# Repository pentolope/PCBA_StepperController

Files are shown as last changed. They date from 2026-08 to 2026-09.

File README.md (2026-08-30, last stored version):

# Quiet Stepper Motor Controller

Single-axis stepper controller using a modern quiet microstepping driver and a small MCU, from a 12–24 V supply at 1.5 A RMS/phase minimum.

`PCBA_StepperController` is a single-axis stepper motor controller built around a modern quiet microstepping driver (the brief offers "a Trinamic-class device" as an example, not a mandate) and a small MCU. The brief fixes the supply range (12–24 V), the phase current target (1.5 A RMS/phase minimum), the presence of current-sense resistors and bulk/ceramic decoupling, STEP/DIR plus UART/SPI configuration access, fault/status signals, and a 4-pin motor connector; it also directs specific attention to driver thermal-pad grounding, high-current phase loops, and keeping current-sense routing away from switching nodes. Everything else — the actual driver and MCU parts, the logic rail, sense-resistor values, connector families, board outline, stackup details, protection and thermal strategy — is left to the design agent. At detail 3/5 this is a mid-specificity brief: the electrical envelope and the layout hazards are named, the implementation is not.

> **This board has not been designed.** There is no schematic, no layout and no
> part selection here — only the brief, a reading of the brief, and the
> scaffolding a design run needs. That is the intended state of this repository,
> not a gap in it.

## What the brief fixes, and what it leaves open

The brief pins down 16 requirements and deliberately leaves
19 decisions to whoever designs the board. The `Source` column says
which is which: `brief` is quoted from [BRIEF.md](BRIEF.md), `metadata` comes
from the benchmark catalogue, and `open` means the brief does not fix it.

| Aspect | Value | Source |
|---|---|---|
| Function | Single-axis stepper controller | brief |
| Motor driver | A modern quiet microstepping driver; a Trinamic-class device is given as an example only, not a mandated part | brief |
| Controller | A small MCU on the board | brief |
| Input supply | 12–24 V | brief |
| Motor current target | 1.5 A RMS/phase minimum | brief |
| Sensing and decoupling | Current-sense resistors plus bulk/ceramic decoupling (values and technologies not fixed) | brief |
| Control and configuration interfaces | STEP/DIR, and UART/SPI configuration access | brief |
| Fault/status | Fault/status signals present (form not fixed) | brief |
| Motor connector | 4-pin (family, pitch and rating not fixed) | brief |
| Layout emphasis called out by the brief | Driver thermal-pad grounding, high-current phase loops, current-sense routing kept away from switching nodes | brief |
| Likely layer count | 4 preferred | metadata |
| Category / difficulty / brief detail | motor-control, difficulty 3, detail 3 | metadata |
| Primary stressors | motor-current routing, driver thermal pad, sense resistors, mixed-signal grounding | metadata |
| Board outline, size, mounting and power-input connector | Not fixed by the brief — design agent's choice | open |

The full split, with the verbatim brief text substantiating every fixed
requirement, is in [board/requirements.md](board/requirements.md) and
machine-readably in [board/requirements.json](board/requirements.json).

**Missing details are design freedom, not permission to fabricate unstated user
requirements.** A choice the brief left open is recorded as a decision, with its
reasoning — never promoted into a requirement.

## Benchmark position

| | |
|---|---|
| Benchmark id | 8 of 32 |
| Category | motor-control |
| Difficulty | 3 / 5 |
| Brief detail | 3 / 5 |
| Likely layer count | 4 preferred |
| Primary stressors | motor-current routing, driver thermal pad, sense resistors, mixed-signal grounding |

This is a motor-control board at difficulty 3/5 and detail 3/5: it tests whether an agent can carry a modest power stage from a stated current and supply envelope through conductor sizing, sense-resistor design and a defensible thermal path, rather than drawing a schematic that only looks right. The four named stressors — motor-current routing, driver thermal pad, sense resistors, mixed-signal grounding — are all layout-and-substantiation problems, so what separates a strong result from a plausible-looking one is whether the physical implementation and its supporting calculations agree. Because the brief names an example device class rather than a part, it also probes whether the agent treats an illustrative example as a requirement.

This repository is one of thirty-two. The suite, the protocol and the results
live in [PCBA_AutoDesignAndTest_Bench](https://github.com/pentolope/PCBA_AutoDesignAndTest_Bench).

## Repository layout

| Path | Contents |
|---|---|
| `BRIEF.md` | the supplied brief — authoritative, preserved byte for byte, never edited |
| `board/requirements.md` | what the brief fixes, what it leaves open, and where decisions get recorded |
| `board/requirements.json` | the same split, machine-readable, each fixed requirement bound to brief text |
| `board/manifest.template.json` | the toolkit's minimum manifest, pre-filled for this board |
| `board/toolchain.json` | where this board's build finds KiCad and the router |
| `benchmark/metadata.json` | the supplied catalogue entry — category, difficulty, detail, stressors |
| `docs/architecture.md` | the decisions this board must make, as questions, unanswered |
| `docs/sources.md` | the classes of evidence the design will have to cite |
| `docs/status.md` | what exists, what does not, and what is deliberately absent |
| `candidates/` | disposable search output, ignored by Git |
| `.claude/skills/` | the accountability-review skill [CLAUDE.md](CLAUDE.md) requires before a push |
| `tooling/PCBA_AutoDesignAndTest` | the shared verification/routing/release toolkit, as a pinned submodule |

## Getting the repository

The toolkit is a submodule and carries KiCad Routing Tools as a submodule of its
own, so clone recursively:

```bash
git clone --recursive https://github.com/pentolope/PCBA_StepperController.git
```

```bash
git submodule update --init --recursive
```

## Designing the board

Generic verification, routing and release logic is **not** written here. It is
consumed from `tooling/PCBA_AutoDesignAndTest`, which is board-agnostic by
construction and must stay that way; this repository owns the board and nothing
else. Start from
[the toolkit's onboarding guide](tooling/PCBA_AutoDesignAndTest/examples/onboarding.md),
and see [CLAUDE.md](CLAUDE.md) for the rules a design run works under.

```bash
python3 tooling/PCBA_AutoDesignAndTest/run.py preflight
```

## Brief integrity

`BRIEF.md` SHA-256 `eb32e622a2161815c687ef267615287b89c1135211a0c5d5494930910a460444`

Every quotation in `board/requirements.json` is bound to those exact bytes. If
the brief ever changes, the bindings are stale by construction — which is the
point of recording the digest.

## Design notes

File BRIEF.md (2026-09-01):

# PCBA_StepperController — Quiet Stepper Motor Controller
## Design brief

Create a single-axis stepper controller using a modern quiet microstepping driver (for example a Trinamic-class device) and a small MCU. Input supply: 12–24 V. Motor current target: 1.5 A RMS/phase minimum. Include current-sense resistors, bulk/ceramic decoupling, STEP/DIR and UART/SPI configuration access, fault/status signals, and a 4-pin motor connector. Pay particular attention to driver thermal-pad grounding, high-current phase loops, and keeping current-sense routing away from switching nodes.

## Functional and electrical requirements

- 1.5 A RMS/phase sustained continuously across the whole 12-24 V range.
- Low-noise microstepping usable as assembled; current, microstep resolution and chopper mode settable over the interface.
- Outputs off at power-up and reset; no phase current until the driver is explicitly enabled.

## Motor drive and current sensing

- One external sense resistor per phase, non-inductive, rated for peak and RMS dissipation, tempco and tolerance inside the recorded accuracy budget.
- Sense value puts 1.5 A RMS/phase (about 2.1 A sine peak) inside the driver's sense-voltage range, with programmable headroom either side.
- Kelvin sensing at the resistor pads, returning only to the driver's sense reference and sharing no copper with phase or supply return current.

## Interfaces and connectors

- 4-pin motor connector A+/A-/B+/B-, keyed against reversed mating, rated for phase current at temperature and retained against vibration.
- STEP/DIR meet the driver's pulse width and setup/hold limits and do not ring enough to double-step.
- Configuration interface carries the pulls and idle states the driver needs and is reachable externally for read-back; diagnostics reach the MCU, at least one interrupt-capable.

## Layout, grounding and thermal

- Exposed pad soldered to copper that is both power-ground connection and heat path, tied through a via array, not a neck or a sense return.
- Phase loops - output, connector, motor, return, sense resistor, ground - as tight as layout allows, enclosing no sense or logic routing.
- Sense pairs routed together, away from output nodes, phase copper and charge-pump nodes; decoupling for the shortest supply-to-ground loop.
- Copper area, plane tie and airflow hold junction temperature under the driver's limit with both phases at full current at 24 V.

## Protection and robustness

- Motor-supply parts rated above 24 V with margin for hot-plug ringing and regenerative rise; reversed polarity does no damage.
- Survives unmating the motor while enabled, and a phase shorted pin-to-pin, to ground or to supply.
- Driver short, open-load and overtemperature detection enabled and reported; drive latches off rather than retrying into a fault.

## Test and bring-up

- Test points with local ground on motor supply, logic rail, STEP, DIR, enable, fault/status and each sense node.
- Rails, register read-back and faults verifiable with no motor fitted; MCU debug accessible.

## Open choices

- Driver device and MCU, subject to quiet microstepping with external sense resistors at 1.5 A RMS/phase or more over 12-24 V and an interrupt-capable fault input.
- UART or SPI for configuration, and whether the logic rail is made on-board or taken from outside.
- Whether STEP/DIR are also exposed to an external motion source, and whether fault/status is surfaced to a human.
- Connector families, board outline and layer count.

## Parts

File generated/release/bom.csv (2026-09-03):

Quantity | Designator | Comment | Footprint | LCSC Part #
4 | C1,C2,C20,C21 | 100uF | Capacitor_SMD:CP_Elec_10x10.5 | C3008515
3 | C3,C4,C12 | 4.7uF | Capacitor_SMD:C_1206_3216Metric | C132170
10 | C5,C6,C8,C10,C11,C13,C14,C17,C18,C19 | 100nF | Capacitor_SMD:C_0603_1608Metric | C113803
1 | C7 | 22nF | Capacitor_SMD:C_0603_1608Metric | C106222
1 | C9 | 2.2uF | Capacitor_SMD:C_0805_2012Metric | C277470
2 | C15,C16 | 10uF | Capacitor_SMD:C_0805_2012Metric | C326595
1 | D1 | SMBJ26A | Diode_SMD:D_SMB | C315992
8 | D2,D3,D4,D5,D6,D7,D8,D9 | TPD1E10B06 | StepperController:TI_X1SON-2_1.0x0.6mm_P0.65mm | C48260
2 | D10,D11 | KT-0603R | LED_SMD:LED_0603_1608Metric | C2286
1 | J1 | KF128-5.08-2P-AA | StepperController:TerminalBlock_KF128-5.08_1x02_P5.08mm | C474952
1 | J2 | B4P-VH | Connector_JST:JST_VH_B4P-VH_1x04_P3.96mm_Vertical | C160317
2 | J3,J4 | KH-2.54PH180-1X5P-L11.5 | Connector_PinHeader_2.54mm:PinHeader_1x05_P2.54mm_Vertical | C2932699
1 | J5 | KH-2.54PH180-1X3P-L11.5 | Connector_PinHeader_2.54mm:PinHeader_1x03_P2.54mm_Vertical | C2932698
1 | L1 | 22uH | StepperController:L_Bourns_SRP4020TA | C1847949
1 | Q1 | Si9407BDY | Package_SO:SOIC-8_3.9x4.9mm_P1.27mm | C141567
5 | R1,R2,R3,R5,R7 | 100k | Resistor_SMD:R_0603_1608Metric | C25803
3 | R4,R6,R10 | 22k | Resistor_SMD:R_0603_1608Metric | C31850
1 | R8 | 12k | Resistor_SMD:R_0603_1608Metric | C22790
4 | R9,R20,R21,R22 | 1k | Resistor_SMD:R_0603_1608Metric | C21190
6 | R11,R12,R16,R17,R18,R19 | 100R | Resistor_SMD:R_0603_1608Metric | C22775
1 | R13 | 10k | Resistor_SMD:R_0603_1608Metric | C25804
2 | R14,R15 | 4.7k | Resistor_SMD:R_0603_1608Metric | C23162
2 | RS1,RS2 | 100mR | Resistor_SMD:R_1206_3216Metric | C5123673
1 | U1 | TMC2226-SA-T | StepperController:HTSSOP-28-1EP_4.4x9.7mm_P0.65mm_EP2.75x6.2mm_SegmentedMask | C705366
1 | U2 | STM32G030K8T6 | Package_QFP:LQFP-32_7x7mm_P0.8mm | C724044
1 | U3 | LMR51430YF | Package_TO_SOT_SMD:SOT-23-6 | C5219261

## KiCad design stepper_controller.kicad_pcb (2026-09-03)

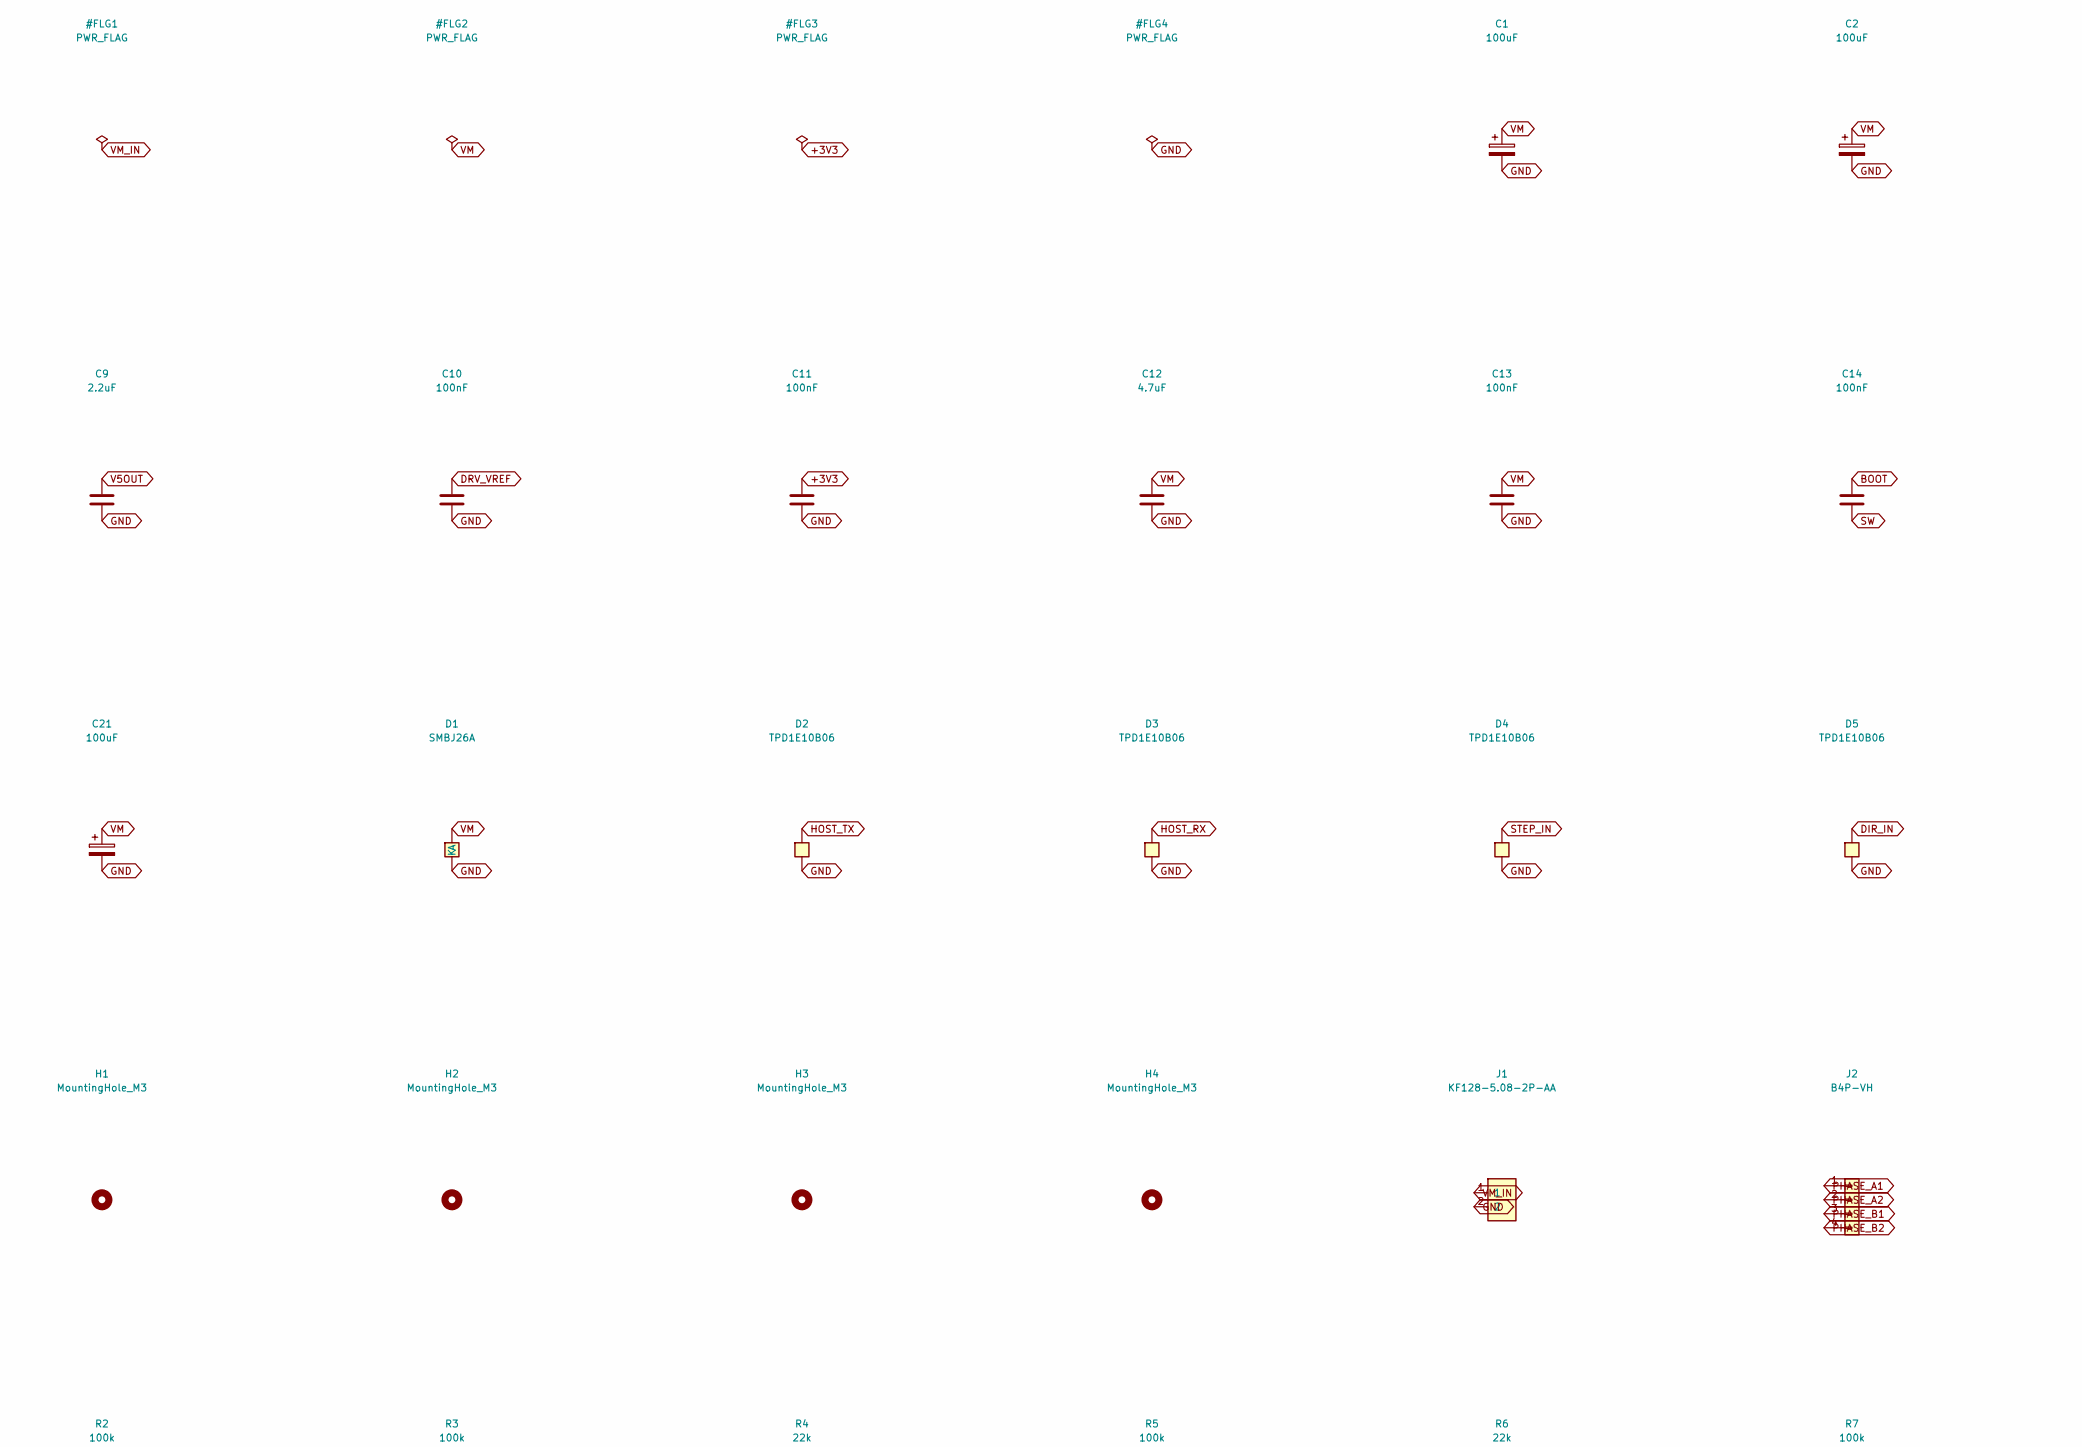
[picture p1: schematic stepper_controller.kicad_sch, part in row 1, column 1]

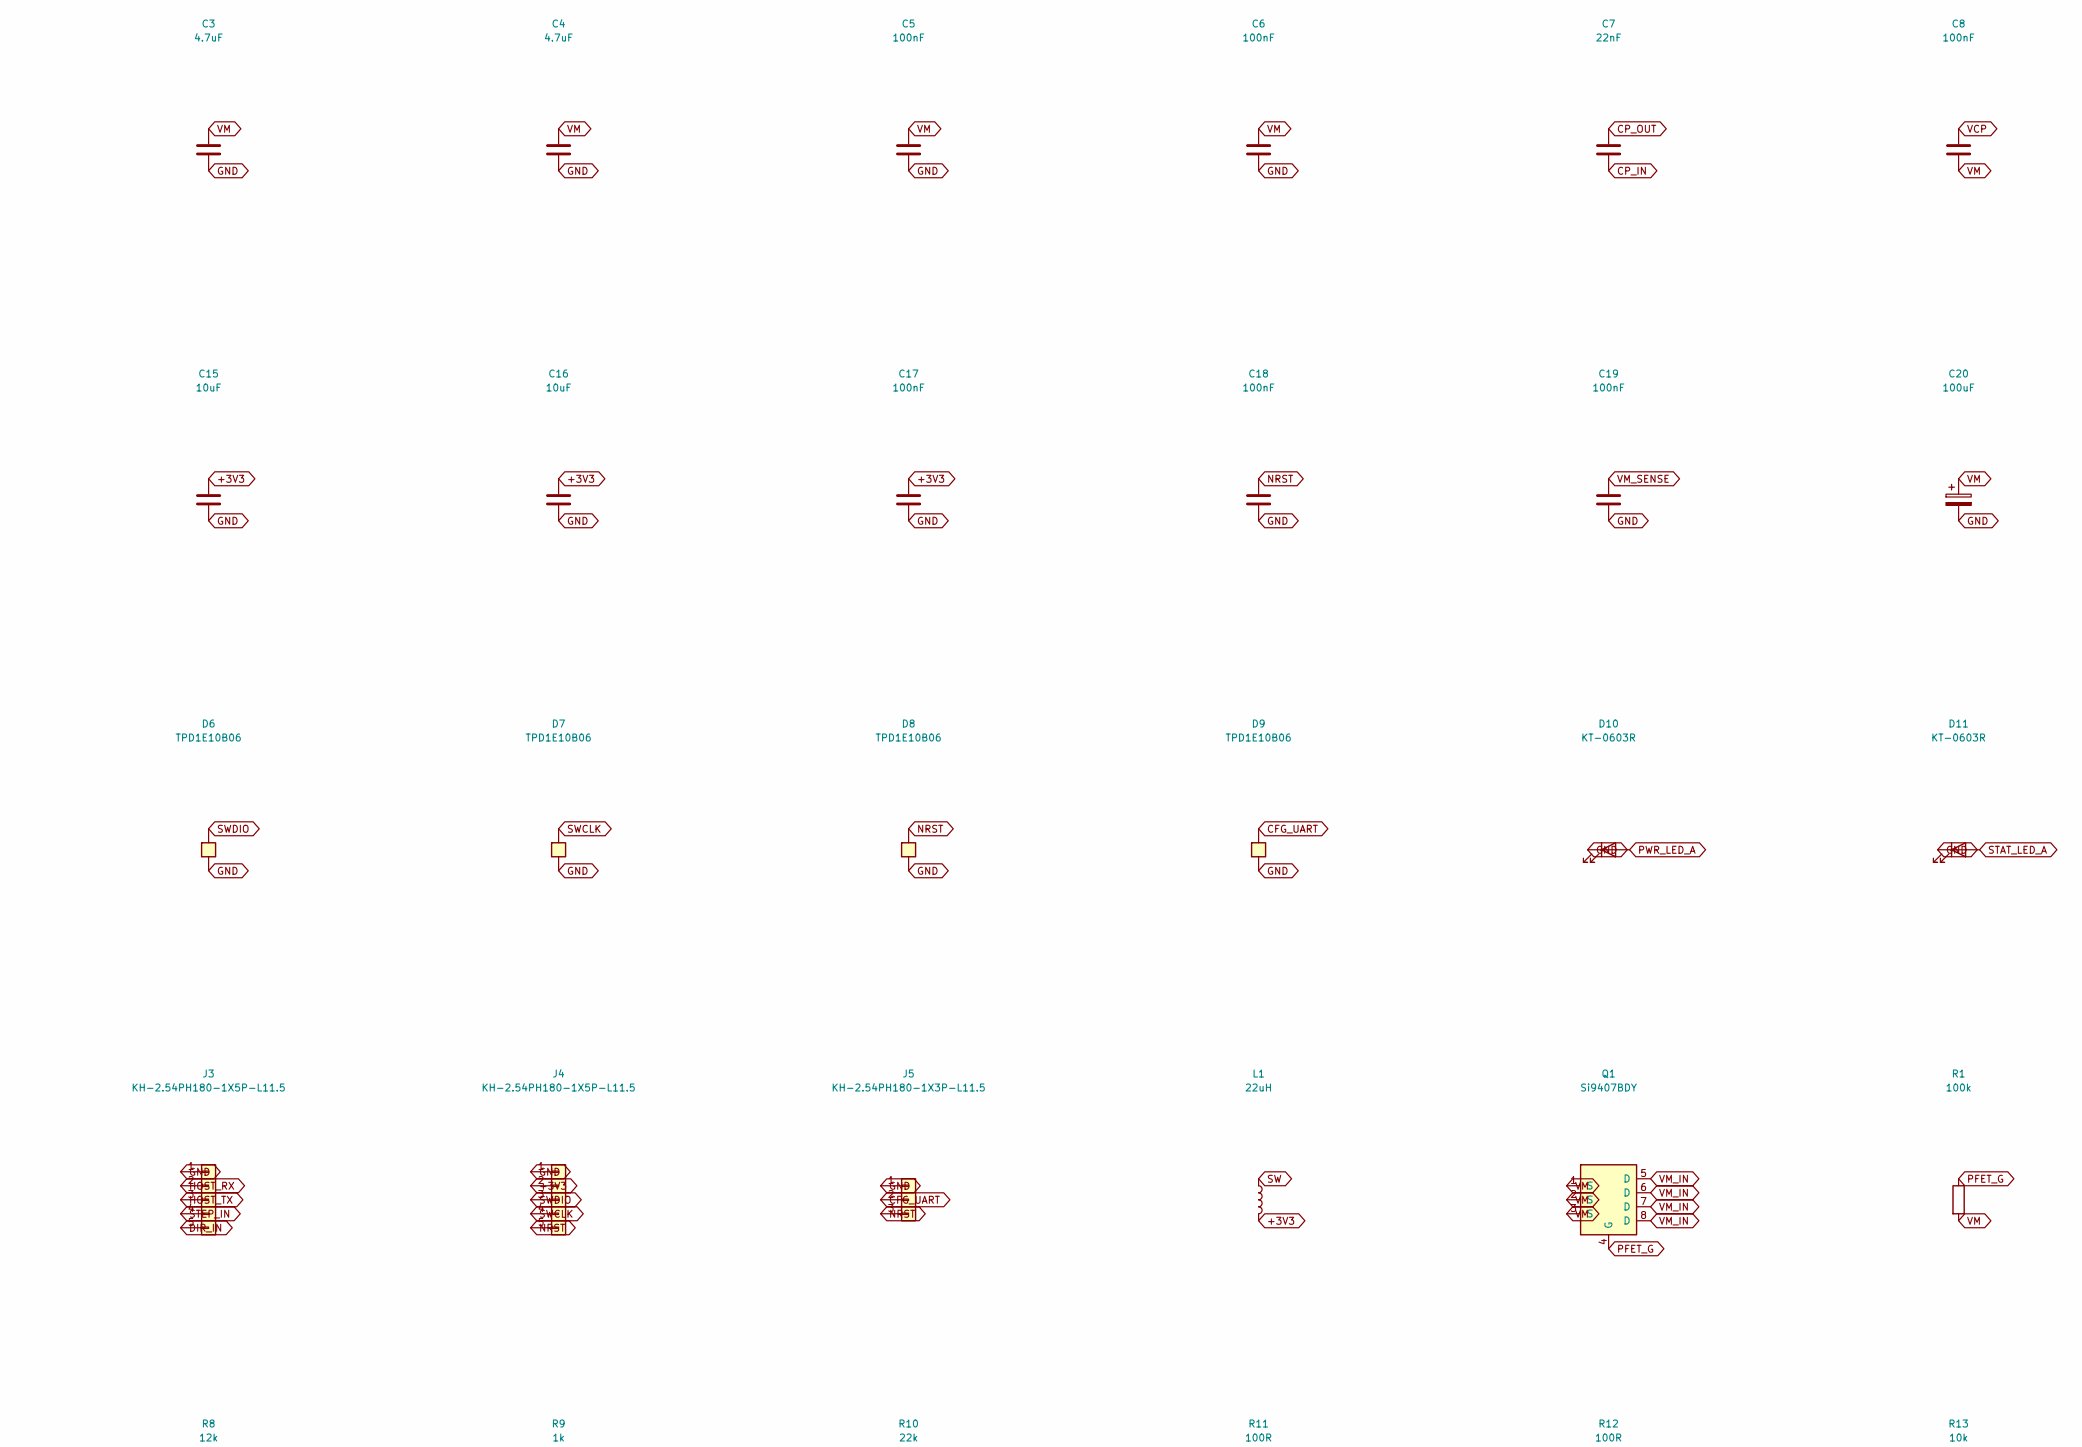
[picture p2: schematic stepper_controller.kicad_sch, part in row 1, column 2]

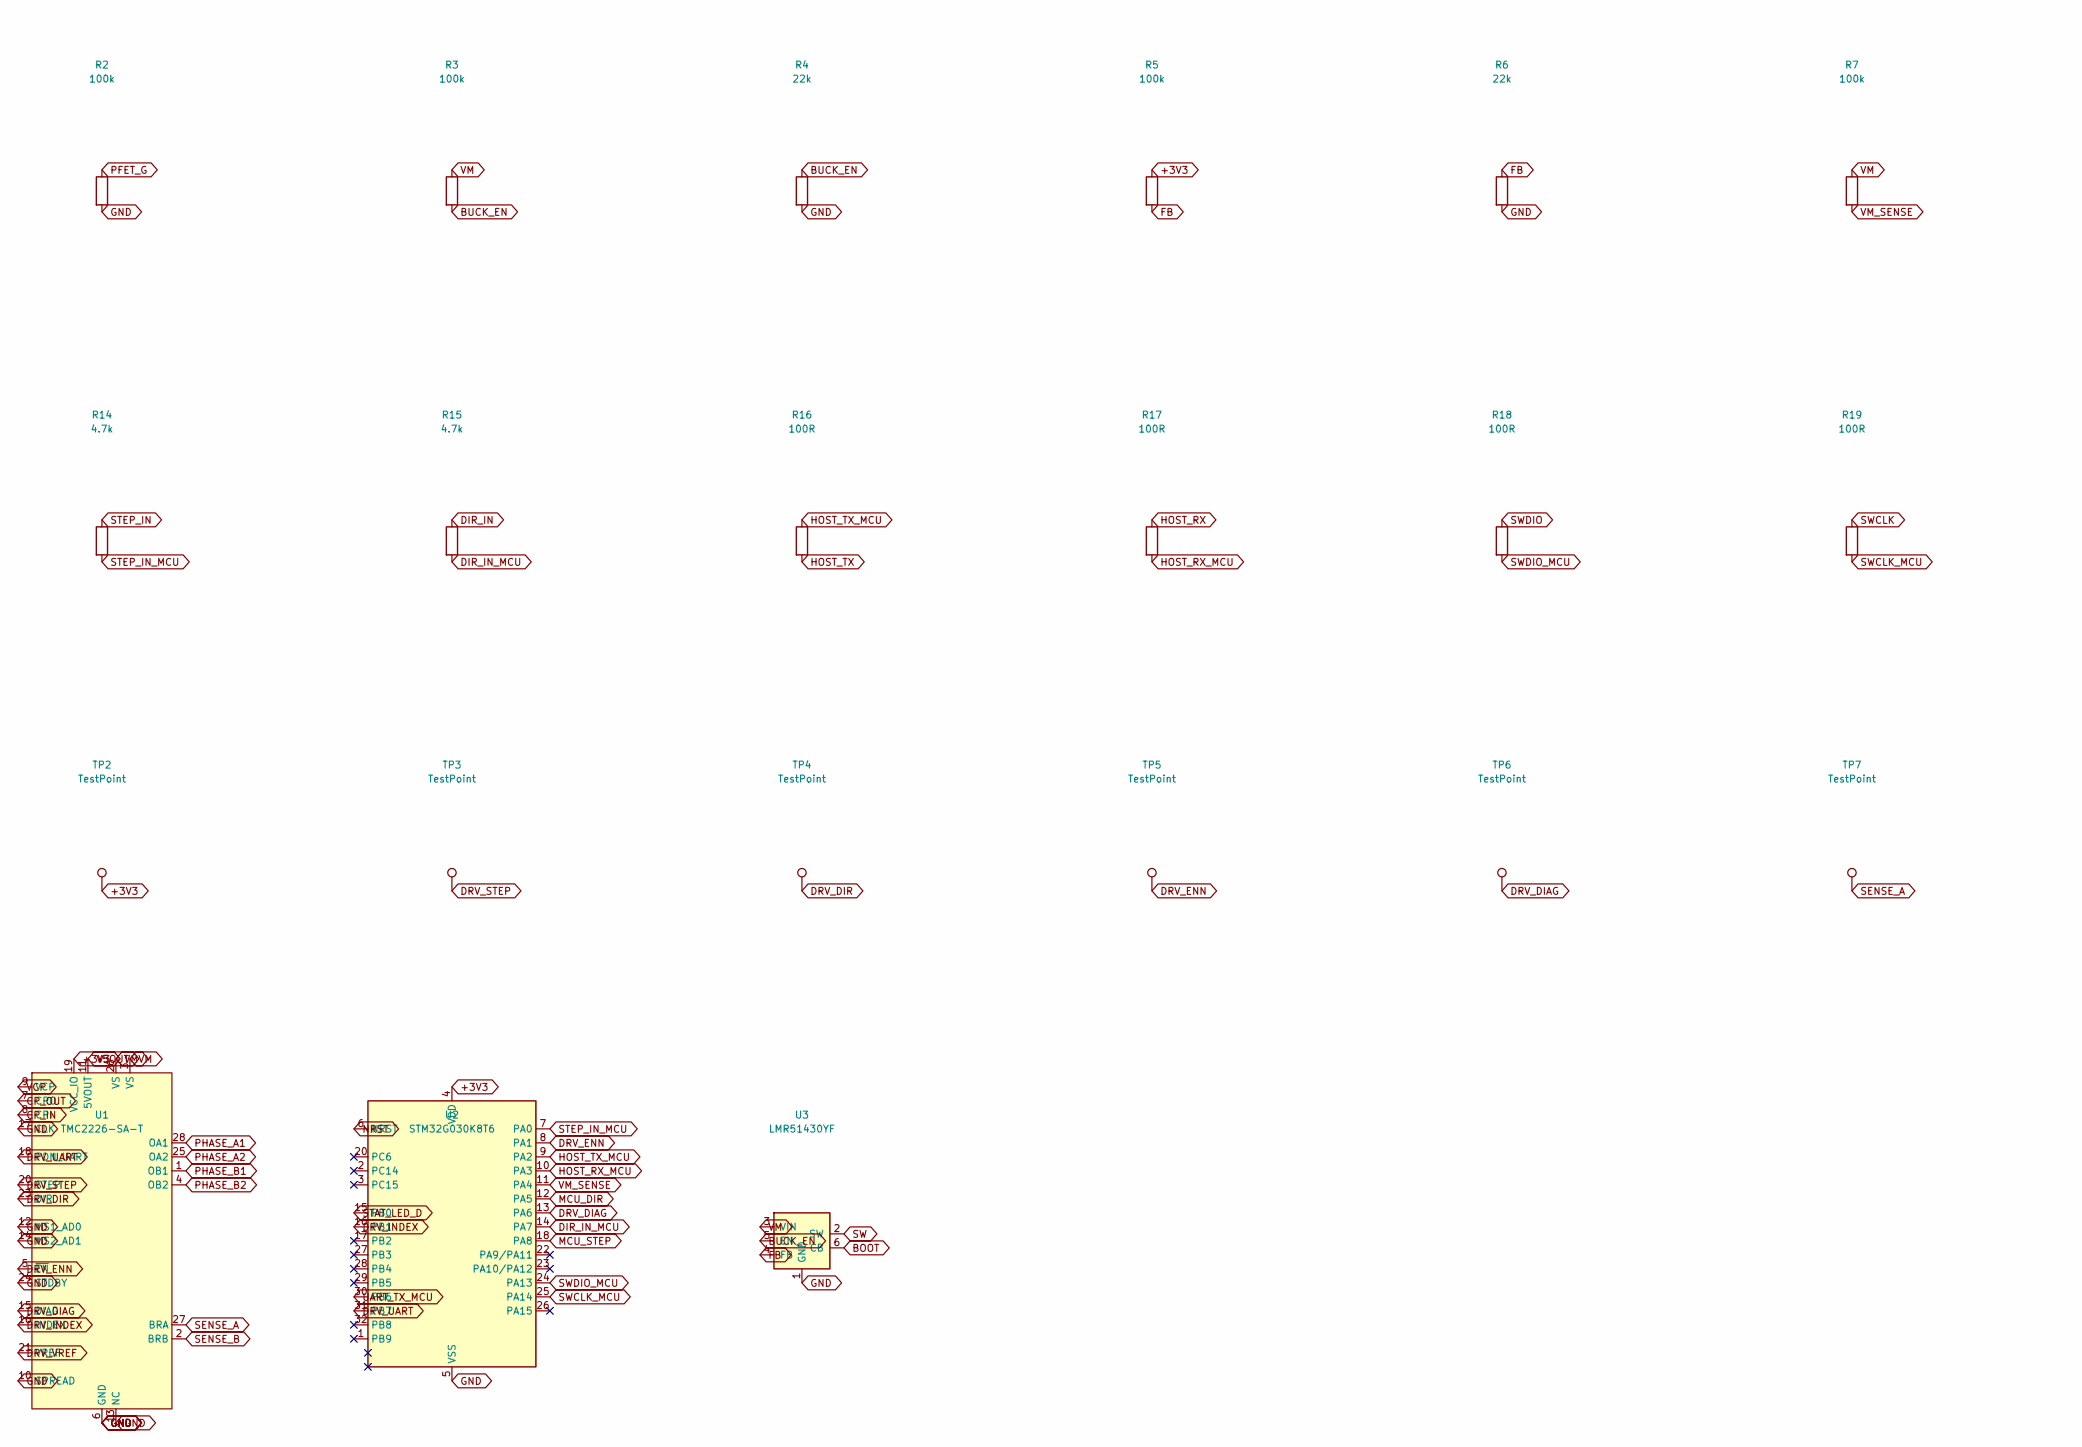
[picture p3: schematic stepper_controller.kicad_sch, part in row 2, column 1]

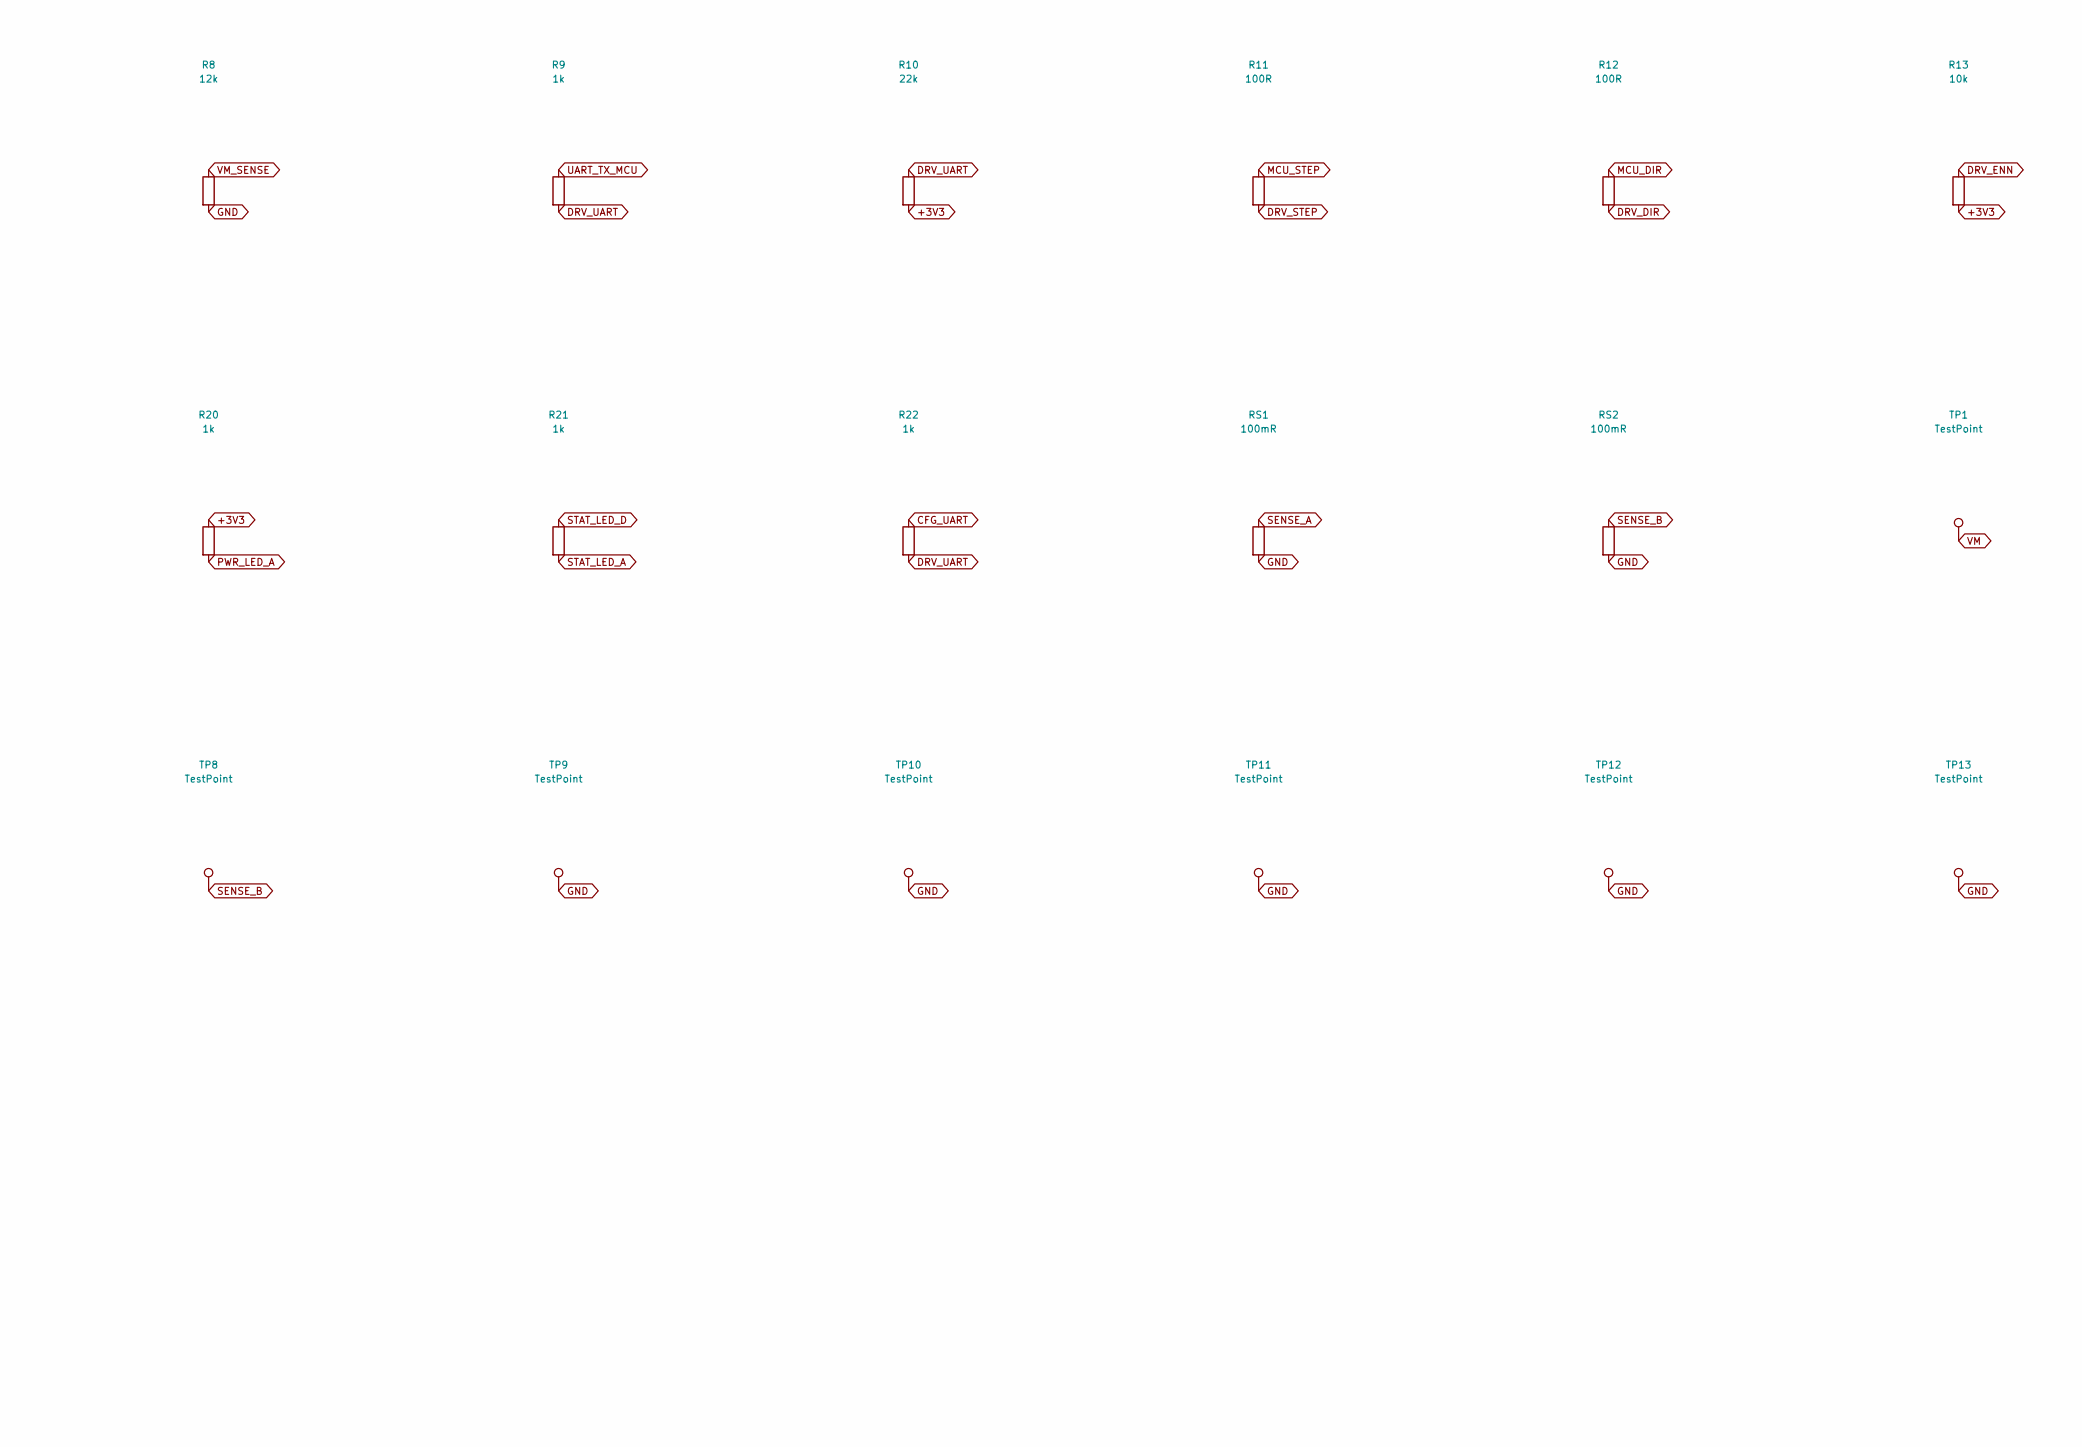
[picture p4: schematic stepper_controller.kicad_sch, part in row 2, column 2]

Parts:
C1, C2, C20, C21: 100uF; CP_Elec_10x10.5; MPN HHXC500ARA101MJA0G; LCSC C3008515
C3, C4, C12: 4.7uF; C_1206_3216Metric; MPN CC1206KKX7R9BB475; LCSC C132170
C5, C6, C8, C10, C11, C13, C14, C17, C18, C19: 100nF; C_0603_1608Metric; MPN CC0603KRX7R0BB104; LCSC C113803
C7: 22nF; C_0603_1608Metric; MPN CC0603KRX7R9BB223; LCSC C106222
C9: 2.2uF; C_0805_2012Metric; MPN CC0805KKX7R8BB225; LCSC C277470
C15, C16: 10uF; C_0805_2012Metric; MPN CC0805KKX7R7BB106; LCSC C326595
D1: SMBJ26A; D_SMB; MPN SMBJ26A; LCSC C315992
D2, D3, D4, D5, D6, D7, D8, D9: TPD1E10B06; TI_X1SON-2_1.0x0.6mm_P0.65mm; MPN TPD1E10B06DPYR; LCSC C48260
D10, D11: KT-0603R; LED_0603_1608Metric; MPN KT-0603R; LCSC C2286
H1, H2, H3, H4: MountingHole_M3; MountingHole_3.2mm_M3
J1: KF128-5.08-2P-AA; TerminalBlock_KF128-5.08_1x02_P5.08mm; MPN KF128-5.08-2P-AA; LCSC C474952
J2: B4P-VH; JST_VH_B4P-VH_1x04_P3.96mm_Vertical; MPN B4P-VH(LF)(SN); LCSC C160317
J3, J4: KH-2.54PH180-1X5P-L11.5; PinHeader_1x05_P2.54mm_Vertical; MPN KH-2.54PH180-1X5P-L11.5; LCSC C2932699
J5: KH-2.54PH180-1X3P-L11.5; PinHeader_1x03_P2.54mm_Vertical; MPN KH-2.54PH180-1X3P-L11.5; LCSC C2932698
L1: 22uH; L_Bourns_SRP4020TA; MPN SRP4020TA-220M; LCSC C1847949
Q1: Si9407BDY; SOIC-8_3.9x4.9mm_P1.27mm; MPN Si9407BDY-T1-GE3; LCSC C141567
R1, R2, R3, R5, R7: 100k; R_0603_1608Metric; MPN 0603WAF1003T5E; LCSC C25803
R4, R6, R10: 22k; R_0603_1608Metric; MPN 0603WAF2202T5E; LCSC C31850
R8: 12k; R_0603_1608Metric; MPN 0603WAF1202T5E; LCSC C22790
R9, R20, R21, R22: 1k; R_0603_1608Metric; MPN 0603WAF1001T5E; LCSC C21190
R11, R12, R16, R17, R18, R19: 100R; R_0603_1608Metric; MPN 0603WAF1000T5E; LCSC C22775
R13: 10k; R_0603_1608Metric; MPN 0603WAF1002T5E; LCSC C25804
R14, R15: 4.7k; R_0603_1608Metric; MPN 0603WAF4701T5E; LCSC C23162
RS1, RS2: 100mR; R_1206_3216Metric; MPN HoLRTX1206-1W-100mR-1%; LCSC C5123673
TP1, TP2, TP3, TP4, TP5, TP6, TP7, TP8, TP9, TP10, TP11, TP12, TP13: TestPoint; TestPoint_Pad_D1.0mm
U1: TMC2226-SA-T; HTSSOP-28-1EP_4.4x9.7mm_P0.65mm_EP2.75x6.2mm_SegmentedMask; MPN TMC2226-SA-T; LCSC C705366
U2: STM32G030K8T6; LQFP-32_7x7mm_P0.8mm; MPN STM32G030K8T6TR; LCSC C724044
U3: LMR51430YF; SOT-23-6; MPN LMR51430YFDDCR; LCSC C5219261

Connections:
+3V3: C11.1, C15.1, C16.1, C17.1, J4.2, L1.2, R5.1, R10.2, R13.2, R20.1, TP2.1, U1.19 (VCC_IO), U2.4 (VDD)
BOOT: C14.1, U3.6 (CB)
BUCK_EN: R3.2, R4.1, U3.5 (EN)
CFG_UART: D9.1 (IO1), J5.2, R22.1
CP_IN: C7.2, U1.8 (CPI)
CP_OUT: C7.1, U1.7 (CPO)
DIR_IN: D5.1 (IO1), J3.5, R15.1
DIR_IN_MCU: R15.2, U2.14 (PA7)
DRV_DIAG: TP6.1, U1.15 (DIAG), U2.13 (PA6)
DRV_DIR: R12.2, TP4.1, U1.23 (DIR)
DRV_ENN: R13.1, TP5.1, U1.5 (~EN), U2.8 (PA1)
DRV_INDEX: U1.16 (INDEX), U2.16 (PB1)
DRV_STEP: R11.2, TP3.1, U1.20 (STEP)
DRV_UART: R9.2, R10.1, R22.2, U1.18 (PDN_UART), U2.31 (PB7)
DRV_VREF: C10.1, U1.21 (VREF)
FB: R5.2, R6.1, U3.4 (FB)
GND: C1.2, C2.2, C3.2, C4.2, C5.2, C6.2, C9.2, C10.2, C11.2, C12.2, C13.2, C15.2, C16.2, C17.2, C18.2, C19.2, C20.2, C21.2, D1.2 (A), D2.2 (IO2), D3.2 (IO2), D4.2 (IO2), D5.2 (IO2), D6.2 (IO2), D7.2 (IO2), D8.2 (IO2), D9.2 (IO2), D10.1 (K), D11.1 (K), J1.2, J3.1, J4.1, J5.1, R2.2, R4.2, R6.2, R8.2, RS1.2, RS2.2, TP9.1, TP10.1, TP11.1, TP12.1, TP13.1, U1.6 (GND), U1.10 (SPREAD), U1.12 (MS1_AD0), U1.13 (NC), U1.14 (MS2_AD1), U1.17 (CLK), U1.22 (GND), U1.24 (STDBY), U1.29 (GND), U2.5 (VSS), U3.1 (GND)
HOST_RX: D3.1 (IO1), J3.2, R17.1
HOST_RX_MCU: R17.2, U2.10 (PA3)
HOST_TX: D2.1 (IO1), J3.3, R16.2
HOST_TX_MCU: R16.1, U2.9 (PA2)
MCU_DIR: R12.1, U2.12 (PA5)
MCU_STEP: R11.1, U2.18 (PA8)
NRST: C18.1, D8.1 (IO1), J4.5, J5.3, U2.6 (NRST)
PFET_G: Q1.4 (G), R1.1, R2.1
PHASE_A1: J2.1, U1.28 (OA1)
PHASE_A2: J2.2, U1.25 (OA2)
PHASE_B1: J2.3, U1.1 (OB1)
PHASE_B2: J2.4, U1.4 (OB2)
PWR_LED_A: D10.2 (A), R20.2
SENSE_A: RS1.1, TP7.1, U1.27 (BRA)
SENSE_B: RS2.1, TP8.1, U1.2 (BRB)
STAT_LED_A: D11.2 (A), R21.2
STAT_LED_D: R21.1, U2.15 (PB0)
STEP_IN: D4.1 (IO1), J3.4, R14.1
STEP_IN_MCU: R14.2, U2.7 (PA0)
SW: C14.2, L1.1, U3.2 (SW)
SWCLK: D7.1 (IO1), J4.4, R19.1
SWCLK_MCU: R19.2, U2.25 (PA14)
SWDIO: D6.1 (IO1), J4.3, R18.1
SWDIO_MCU: R18.2, U2.24 (PA13)
UART_TX_MCU: R9.1, U2.30 (PB6)
V5OUT: C9.1, U1.11 (5VOUT)
VCP: C8.1, U1.9 (VCP)
VM: C1.1, C2.1, C3.1, C4.1, C5.1, C6.1, C8.2, C12.1, C13.1, C20.1, C21.1, D1.1 (K), Q1.1 (S), Q1.2 (S), Q1.3 (S), R1.2, R3.1, R7.1, TP1.1, U1.3 (VS), U1.26 (VS), U3.3 (VIN)
VM_IN: J1.1, Q1.5 (D), Q1.6 (D), Q1.7 (D), Q1.8 (D)
VM_SENSE: C19.1, R7.2, R8.1, U2.11 (PA4)

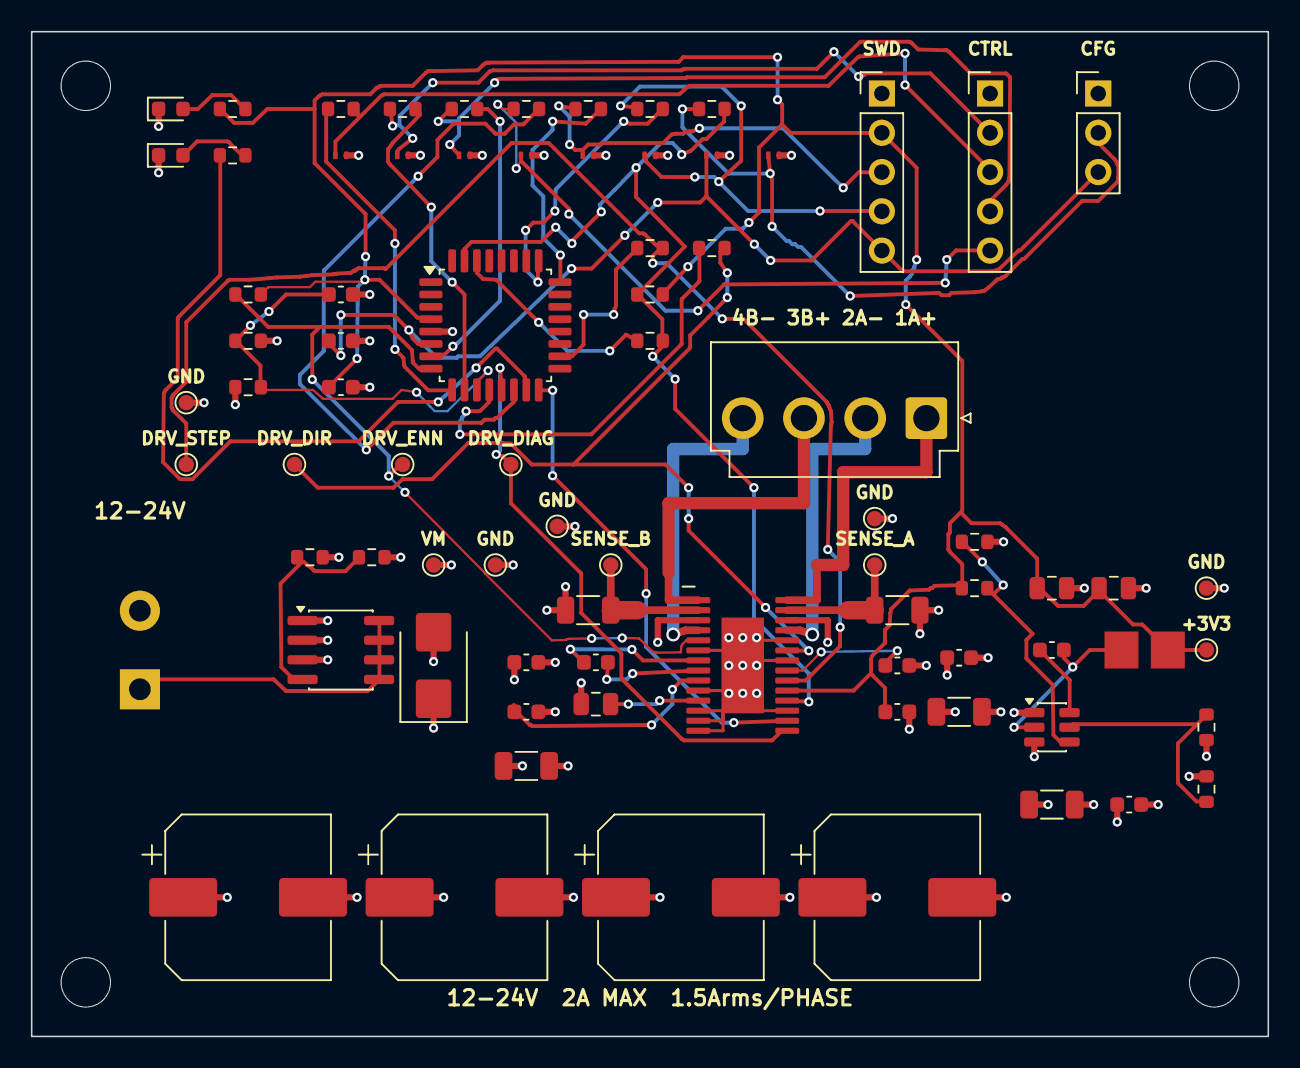
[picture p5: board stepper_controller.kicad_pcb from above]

Board: 4 copper layers, 80.0 x 65.0 mm, 83 parts (0 on the bottom side), 47 nets.

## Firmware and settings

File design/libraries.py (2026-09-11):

from __future__ import annotations

import os
import sys

from . import netlist

REPO_ROOT = os.path.dirname(os.path.dirname(os.path.abspath(__file__)))
LIBRARY_NAME = netlist.LIBRARY_NAME
SYMBOL_LIB_PATH = os.path.join(REPO_ROOT, "library",
                               LIBRARY_NAME + ".kicad_sym")
FOOTPRINT_DIR = os.path.join(REPO_ROOT, "library", LIBRARY_NAME + ".pretty")
SYM_LIB_TABLE = os.path.join(REPO_ROOT, "sym-lib-table")
FP_LIB_TABLE = os.path.join(REPO_ROOT, "fp-lib-table")

SYMBOL_LIB_VERSION = "20251024"
FOOTPRINT_VERSION = "20260206"
GENERATOR = "stepper-controller-design-source"

BUCK_SYMBOL_NAME = "LMR51430"
BUCK_PINS = [("3", "VIN", "power_in", "left"),
             ("5", "EN", "input", "left"),
             ("4", "FB", "input", "left"),
             ("2", "SW", "output", "right"),
             ("6", "CB", "passive", "right"),
             ("1", "GND", "power_in", "bottom")]
BUCK_DATASHEET = "https://www.ti.com/lit/ds/symlink/lmr51430.pdf"

PFET_SYMBOL_NAME = "Si9407BDY"
PFET_DATASHEET = "https://www.vishay.com/docs/69902/si9407bdy.pdf"

TVS_SYMBOL_NAME = "TVS_Unidirectional"
ESD_SYMBOL_NAME = "TPD1E10B06"
ESD_DATASHEET = "https://www.ti.com/lit/ds/symlink/tpd1e10b06.pdf"
TERMINAL_SYMBOL_NAME = "ScrewTerminal_1x02"
TERMINAL_FOOTPRINT_FILTER = "TerminalBlock*"

#: TI DPY0002A, drawing 4224561/C (SLLSEB1G): two 0.30 x 0.50 lands on
#: 0.70 centres; package outline 1.10 x 0.70.
X1SON_FOOTPRINT_NAME = "TI_X1SON-2_1.0x0.6mm_P0.65mm"
X1SON_PAD_SIZE_MM = (0.30, 0.50)
X1SON_PAD_PITCH_MM = 0.70
X1SON_BODY_MM = (1.10, 0.70)
X1SON_COURTYARD_MARGIN_MM = 0.15

#: Cixi Kefa KF128-5.08 drawing rev A: two 1.40 +0.10/-0.00 holes on
#: 5.08 +/-0.03 centres; body 10.70 deep with the pin row 5.40 from the
#: wire-entry face.
KF128_FOOTPRINT_NAME = "TerminalBlock_KF128-5.08_1x02_P5.08mm"
KF128_PITCH_MM = 5.08
KF128_DRILL_MM = 1.40
KF128_PAD_DIAMETER_MM = 2.60
KF128_BODY_DEPTH_MM = 10.70
KF128_PIN_TO_ENTRY_FACE_MM = 5.40
KF128_COURTYARD_MARGIN_MM = 0.25

#: Bourns SRP4020TA recommended layout: two 2.20 x 2.40 lands, 5.20 overall.
#: Body 4.45 x 4.06.
INDUCTOR_FOOTPRINT_NAME = "L_Bourns_SRP4020TA"
INDUCTOR_PAD_MM = (2.20, 2.40)
INDUCTOR_LAND_SPAN_MM = 5.20
INDUCTOR_BODY_MM = (4.45, 4.06)
INDUCTOR_COURTYARD_MARGIN_MM = 0.25

#: HTSSOP-28 land pattern for the driver. The signal lands are the standard
#: ones; the exposed pad carries copper with no mask, and the mask and paste
#: are cut into windows so that every thermal via lands on a mask dam.
HTSSOP_FOOTPRINT_NAME = (
    "HTSSOP-28-1EP_4.4x9.7mm_P0.65mm_EP2.75x6.2mm_SegmentedMask")
HTSSOP_PIN_COUNT = 28
HTSSOP_PITCH_MM = 0.65
HTSSOP_PAD_MM = (1.55, 0.40)
HTSSOP_ROW_OFFSET_MM = 2.875
HTSSOP_BODY_MM = (4.40, 9.70)
HTSSOP_EP_MM = (2.75, 6.20)
HTSSOP_MASK_WINDOWS = 4
HTSSOP_MASK_DAM_MM = 1.00
HTSSOP_VIA_PAD_MM = netlist.THERMAL_VIA_PAD_MM
HTSSOP_VIA_DRILL_MM = netlist.THERMAL_VIA_DRILL_MM
HTSSOP_VIA_COLUMNS_MM = (-0.9, 0.0, 0.9)
HTSSOP_COURTYARD_MARGIN_MM = 0.25


def mask_window_height_mm():
    return ((HTSSOP_EP_MM[1] - HTSSOP_MASK_DAM_MM * (HTSSOP_MASK_WINDOWS - 1))
            / HTSSOP_MASK_WINDOWS)


def mask_window_centres_mm():
    height = mask_window_height_mm()
    pitch = height + HTSSOP_MASK_DAM_MM
    first = -(HTSSOP_EP_MM[1] - height) / 2.0
    return tuple(first + pitch * index
                 for index in range(HTSSOP_MASK_WINDOWS))


def thermal_via_rows_mm():
    centres = mask_window_centres_mm()
    return tuple((centres[index] + centres[index + 1]) / 2.0
                 for index in range(len(centres) - 1))


def thermal_via_positions_mm():
    return tuple((x, y) for y in thermal_via_rows_mm()
                 for x in HTSSOP_VIA_COLUMNS_MM)


#: The share of the exposed pad the stencil must still print after
#: the windows are cut out of it.
MIN_PASTE_COVERAGE = 0.50


def paste_coverage_fraction():
    area = (HTSSOP_EP_MM[0] * mask_window_height_mm() * HTSSOP_MASK_WINDOWS)
    return area / (HTSSOP_EP_MM[0] * HTSSOP_EP_MM[1])


def thermal_via_to_mask_clearance_mm():
    return ((HTSSOP_MASK_DAM_MM - HTSSOP_VIA_PAD_MM) / 2.0)


def htssop_pad_positions_mm():
    span = HTSSOP_PITCH_MM * (HTSSOP_PIN_COUNT // 2 - 1)
    positions = {}
    for index in range(HTSSOP_PIN_COUNT // 2):
        y = -span / 2.0 + HTSSOP_PITCH_MM * index
        positions[str(index + 1)] = (-HTSSOP_ROW_OFFSET_MM, y)
        positions[str(HTSSOP_PIN_COUNT - index)] = (HTSSOP_ROW_OFFSET_MM, y)
    return positions


# ---------------------------------------------------------------------------
# symbols

def _effects():
    return ("\n\t\t\t\t(effects\n\t\t\t\t\t(font\n"
            "\t\t\t\t\t\t(size 1.27 1.27)\n\t\t\t\t\t)\n\t\t\t\t)")


def _symbol_property(key, value, index, hide):
    hidden = "\n\t\t\t(hide yes)" if hide else ""
    return ('\t\t(property "%s" "%s"\n\t\t\t(at 0 %.2f 0)%s\n'
            '\t\t\t(effects\n\t\t\t\t(font\n\t\t\t\t\t(size 1.27 1.27)\n'
            '\t\t\t\t)\n\t\t\t)\n\t\t)\n'
            % (key, value, 17.78 - 2.54 * index, hidden))


def _pin_text(kind, x, y, angle, name, number):
    return ('\t\t\t(pin %s line\n\t\t\t\t(at %.2f %.2f %d)\n'
            '\t\t\t\t(length 2.54)\n'
            '\t\t\t\t(name "%s"%s\n\t\t\t\t)\n'
            '\t\t\t\t(number "%s"%s\n\t\t\t\t)\n\t\t\t)'
            % (kind, x, y, angle, name, _effects(), number, _effects()))


def _rectangle(half_x, half_y):
    return ['\t\t\t(rectangle',
            '\t\t\t\t(start %.2f %.2f)' % (-half_x, half_y),
            '\t\t\t\t(end %.2f %.2f)' % (half_x, -half_y),
            '\t\t\t\t(stroke\n\t\t\t\t\t(width 0.254)\n'
            '\t\t\t\t\t(type default)\n\t\t\t\t)',
            '\t\t\t\t(fill\n\t\t\t\t\t(type background)\n\t\t\t\t)',
            '\t\t\t)']


def _placed_pin(number, pin_name, kind, side, placed_pins, half_x, half_y):
    same_side = [entry for entry in placed_pins if entry[3] == side]
    index = same_side.index((number, pin_name, kind, side))
    span = 2.54 * (len(same_side) - 1) / 2.0
    if side == "left":
        return _pin_text(kind, -half_x - 2.54, span - 2.54 * index, 0,
                         pin_name, number)
    if side == "right":
        return _pin_text(kind, half_x + 2.54, span - 2.54 * index, 180,
                         pin_name, number)
    if side == "bottom":
        return _pin_text(kind, 2.54 * index - span, -half_y - 2.54, 90,
                         pin_name, number)
    return _pin_text(kind, 2.54 * index - span, half_y + 2.54, 270,
                     pin_name, number)


def _boxed_symbol(name, reference_prefix, value, footprint, datasheet,
                  placed_pins, half_x, half_y, footprint_filter=None):
    lines = ['\t(symbol "%s"' % name,
             '\t\t(pin_names\n\t\t\t(offset 1.016)\n\t\t)',
             '\t\t(exclude_from_sim no)',
             '\t\t(in_bom yes)',
             '\t\t(on_board yes)',
             _symbol_property("Reference", reference_prefix, 0,
                              False).rstrip("\n"),
             _symbol_property("Value", value, 1, False).rstrip("\n"),
             _symbol_property("Footprint", footprint, 2, True).rstrip("\n"),
             _symbol_property("Datasheet", datasheet, 3, True).rstrip("\n")]
    if footprint_filter is not None:
        lines.append(_symbol_property("ki_fp_filters", footprint_filter, 4,
                                      True).rstrip("\n"))
    lines.append('\t\t(symbol "%s_0_1"' % name)
    lines.extend(_rectangle(half_x, half_y))
    lines.append('\t\t)')
    lines.append('\t\t(symbol "%s_1_1"' % name)
    for number, pin_name, kind, side in placed_pins:
        lines.append(_placed_pin(number, pin_name, kind, side, placed_pins,
                                 half_x, half_y))
    lines.append('\t\t)')
    lines.append('\t)')
    return "\n".join(lines)


def buck_symbol_text():
    return _boxed_symbol(
        BUCK_SYMBOL_NAME, "U", BUCK_SYMBOL_NAME,
        "Package_TO_SOT_SMD:SOT-23-6", BUCK_DATASHEET, list(BUCK_PINS),
        5.08, 5.08, footprint_filter="SOT?23*")


def pfet_symbol_text():
    placed = [(number, "S", "passive", "left")
              for number in netlist.PFET_SOURCE_PINS]
    placed.append((netlist.PFET_GATE_PIN, "G", "input", "bottom"))
    placed.extend((number, "D", "passive", "right")
                  for number in netlist.PFET_DRAIN_PINS)
    return _boxed_symbol(
        PFET_SYMBOL_NAME, "Q", PFET_SYMBOL_NAME,
        "Package_SO:SOIC-8_3.9x4.9mm_P1.27mm", PFET_DATASHEET, placed,
        5.08, 6.35, footprint_filter="SOIC*3.9x4.9mm*P1.27mm*")


def tvs_symbol_text():
    return "\n".join([
        '\t(symbol "%s"' % TVS_SYMBOL_NAME,
        '\t\t(pin_numbers\n\t\t\t(hide yes)\n\t\t)',
        '\t\t(pin_names\n\t\t\t(offset 1.016)\n\t\t)',
        '\t\t(exclude_from_sim no)',
        '\t\t(in_bom yes)',
        '\t\t(on_board yes)',
        _symbol_property("Reference", "D", 0, False).rstrip("\n"),
        _symbol_property("Value", TVS_SYMBOL_NAME, 1, False).rstrip("\n"),
        _symbol_property("Footprint", "Diode_SMD:D_SMB", 2,
                         True).rstrip("\n"),
        _symbol_property("Datasheet", "", 3, True).rstrip("\n"),
        _symbol_property("ki_fp_filters", "D?SMB*", 4, True).rstrip("\n"),
        '\t\t(symbol "%s_0_1"' % TVS_SYMBOL_NAME,
        '\t\t\t(rectangle',
        '\t\t\t\t(start -1.27 1.27)',
        '\t\t\t\t(end 1.27 -1.27)',
        '\t\t\t\t(stroke\n\t\t\t\t\t(width 0.254)\n'
        '\t\t\t\t\t(type default)\n\t\t\t\t)',
        '\t\t\t\t(fill\n\t\t\t\t\t(type background)\n\t\t\t\t)',
        '\t\t\t)',
        '\t\t)',
        '\t\t(symbol "%s_1_1"' % TVS_SYMBOL_NAME,
        _pin_text("passive", 0.0, 3.81, 270, "K", "1"),
        _pin_text("passive", 0.0, -3.81, 90, "A", "2"),
        '\t\t)',
        '\t)',
    ])


def esd_symbol_text():
    return "\n".join([
        '\t(symbol "%s"' % ESD_SYMBOL_NAME,
        '\t\t(pin_numbers\n\t\t\t(hide yes)\n\t\t)',
        '\t\t(pin_names\n\t\t\t(offset 1.016)\n\t\t\t(hide yes)\n\t\t)',
        '\t\t(exclude_from_sim no)',
        '\t\t(in_bom yes)',
        '\t\t(on_board yes)',
        _symbol_property("Reference", "D", 0, False).rstrip("\n"),
        _symbol_property("Value", ESD_SYMBOL_NAME, 1, False).rstrip("\n"),
        _symbol_property("Footprint", "%s:%s" % (LIBRARY_NAME,
                                                 X1SON_FOOTPRINT_NAME),
                         2, True).rstrip("\n"),
        _symbol_property("Datasheet", ESD_DATASHEET, 3, True).rstrip("\n"),
        _symbol_property("ki_fp_filters", X1SON_FOOTPRINT_NAME, 4,
                         True).rstrip("\n"),
        '\t\t(symbol "%s_0_1"' % ESD_SYMBOL_NAME,
        '\t\t\t(rectangle',
        '\t\t\t\t(start -1.27 1.27)',
        '\t\t\t\t(end 1.27 -1.27)',
        '\t\t\t\t(stroke\n\t\t\t\t\t(width 0.254)\n'
        '\t\t\t\t\t(type default)\n\t\t\t\t)',
        '\t\t\t\t(fill\n\t\t\t\t\t(type background)\n\t\t\t\t)',
        '\t\t\t)',
        '\t\t)',
        '\t\t(symbol "%s_1_1"' % ESD_SYMBOL_NAME,
        _pin_text("passive", 0.0, 3.81, 270, "IO1", "1"),
        _pin_text("passive", 0.0, -3.81, 90, "IO2", "2"),
        '\t\t)',
        '\t)',
    ])


def terminal_symbol_text():
    lines = ['\t(symbol "%s"' % TERMINAL_SYMBOL_NAME,
             '\t\t(pin_names\n\t\t\t(offset 1.016)\n\t\t)',
             '\t\t(exclude_from_sim yes)',
             '\t\t(in_bom yes)',
             '\t\t(on_board yes)',
             _symbol_property("Reference", "J", 0, False).rstrip("\n"),
             _symbol_property("Value", TERMINAL_SYMBOL_NAME, 1,
                              False).rstrip("\n"),
             _symbol_property("Footprint", "%s:%s" % (LIBRARY_NAME,
                                                      KF128_FOOTPRINT_NAME),
                              2, True).rstrip("\n"),
             _symbol_property("Datasheet", "", 3, True).rstrip("\n"),
             _symbol_property("ki_fp_filters", TERMINAL_FOOTPRINT_FILTER, 4,
                              True).rstrip("\n"),
             '\t\t(symbol "%s_0_1"' % TERMINAL_SYMBOL_NAME]
    lines.extend(_rectangle(2.54, 3.81))
    lines.append('\t\t)')
    lines.append('\t\t(symbol "%s_1_1"' % TERMINAL_SYMBOL_NAME)
    for index, pin_name in enumerate(("1", "2")):
        lines.append(_pin_text("passive", -5.08, 1.27 - 2.54 * index, 0,
                               pin_name, str(index + 1)))
    lines.append('\t\t)')
    lines.append('\t)')
    return "\n".join(lines)


def symbol_library_text():
    body = [buck_symbol_text(), esd_symbol_text(), pfet_symbol_text(),
            terminal_symbol_text(), tvs_symbol_text()]
    return "\n".join([
        '(kicad_symbol_lib',
        '\t(version %s)' % SYMBOL_LIB_VERSION,
        '\t(generator "%s")' % GENERATOR,
        '\t(generator_version "10.0")',
    ] + body + [')']) + "\n"


# ---------------------------------------------------------------------------
# footprints

def _outline(layer, half_x, half_y, thickness, start_y=None, end_y=None):
    top = half_y if start_y is None else start_y
    bottom = -half_y if end_y is None else end_y
    return ('\t(fp_rect\n\t\t(start %.3f %.3f)\n\t\t(end %.3f %.3f)\n'
            '\t\t(stroke\n\t\t\t(width %.2f)\n\t\t\t(type default)\n\t\t)\n'
            '\t\t(fill none)\n\t\t(layer "%s")\n\t)'
            % (-half_x, top, half_x, bottom, thickness, layer))


def _footprint_header(name, descr, tags, attr, ref_y, value_y, size,
                      thickness, uid):
    return [
        '(footprint "%s"' % name,
        '\t(version %s)' % FOOTPRINT_VERSION,
        '\t(generator "%s")' % GENERATOR,
        '\t(generator_version "10.0")',
        '\t(layer "F.Cu")',
        '\t(descr "%s")' % descr,
        '\t(tags "%s")' % tags,
        '\t(attr %s)' % attr,
        '\t(property "Reference" "REF**"\n\t\t(at 0 %.2f 0)\n'
        '\t\t(layer "F.SilkS")\n\t\t(uuid "00000000-0000-0000-0000-'
        '0000000000%02d")\n\t\t(effects\n\t\t\t(font\n\t\t\t\t(size %.1f %.1f)'
        '\n\t\t\t\t(thickness %.2f)\n\t\t\t)\n\t\t)\n\t)'
        % (ref_y, uid, size, size, thickness),
        '\t(property "Value" "%s"\n\t\t(at 0 %.2f 0)\n'
        '\t\t(layer "F.Fab")\n\t\t(uuid "00000000-0000-0000-0000-'
        '0000000000%02d")\n\t\t(effects\n\t\t\t(font\n\t\t\t\t(size %.1f %.1f)'
        '\n\t\t\t\t(thickness %.2f)\n\t\t\t)\n\t\t)\n\t)'
        % (name, value_y, uid + 1, size, size, thickness),
    ]


def x1son_footprint_text():
    width, height = X1SON_PAD_SIZE_MM
    offset = X1SON_PAD_PITCH_MM / 2.0
    body_x, body_y = (value / 2.0 for value in X1SON_BODY_MM)
    court_x = body_x + X1SON_COURTYARD_MARGIN_MM
    court_y = body_y + X1SON_COURTYARD_MARGIN_MM
    pads = []
    for number, sign in (("1", -1.0), ("2", 1.0)):
        pads.append(
            '\t(pad "%s" smd roundrect\n\t\t(at %.3f 0)\n'
            '\t\t(size %.3f %.3f)\n\t\t(layers "F.Cu" "F.Paste" "F.Mask")\n'
            '\t\t(roundrect_rratio 0.1667)\n\t)'
            % (number, sign * offset, width, height))
    outline = [_outline("F.CrtYd", court_x, court_y, 0.05),
               _outline("F.Fab", body_x, body_y, 0.1)]
    return "\n".join(_footprint_header(
        X1SON_FOOTPRINT_NAME,
        "TI DPY0002A land pattern, SLLSEB1G drawing 4224561/C",
        "X1SON DPY TVS", "smd", -1.2, 1.2, 0.6, 0.1, 1)
        + outline + pads + [')']) + "\n"


def kf128_footprint_text():
    half_pitch = KF128_PITCH_MM / 2.0
    front = -KF128_PIN_TO_ENTRY_FACE_MM
    back = KF128_BODY_DEPTH_MM - KF128_PIN_TO_ENTRY_FACE_MM
    half_width = KF128_PITCH_MM
    margin = KF128_COURTYARD_MARGIN_MM
    pads = []
    for number, sign in (("1", -1.0), ("2", 1.0)):
        pads.append(
            '\t(pad "%s" thru_hole %s\n\t\t(at %.3f 0)\n'
            '\t\t(size %.3f %.3f)\n\t\t(drill %.3f)\n'
            '\t\t(layers "*.Cu" "*.Mask")\n\t)'
            % (number, "rect" if number == "1" else "circle",
               sign * half_pitch, KF128_PAD_DIAMETER_MM,
               KF128_PAD_DIAMETER_MM, KF128_DRILL_MM))
    outline = [
        _outline("F.CrtYd", half_width + margin, 0, 0.05,
                 start_y=back + margin, end_y=front - margin),
        _outline("F.Fab", half_width, 0, 0.1, start_y=back, end_y=front),
    ]
    return "\n".join(_footprint_header(
        KF128_FOOTPRINT_NAME,
        "Cixi Kefa KF128-5.08 2-pole screw terminal, PCB layout from drawing "
        "KF128-5.08 rev A",
        "terminal block screw 5.08mm", "through_hole",
        front - 1.2, back + 1.2, 1.0, 0.15, 11)
        + outline + pads + [')']) + "\n"


def inductor_footprint_text():
    pad_x, pad_y = INDUCTOR_PAD_MM
    offset = (INDUCTOR_LAND_SPAN_MM - pad_x) / 2.0
    body_x, body_y = (value / 2.0 for value in INDUCTOR_BODY_MM)
    court_x = max(offset + pad_x / 2.0, body_x) + INDUCTOR_COURTYARD_MARGIN_MM
    court_y = max(pad_y / 2.0, body_y) + INDUCTOR_COURTYARD_MARGIN_MM
    pads = []
    for number, sign in (("1", -1.0), ("2", 1.0)):
        pads.append(
            '\t(pad "%s" smd rect\n\t\t(at %.3f 0)\n'
            '\t\t(size %.3f %.3f)\n\t\t(layers "F.Cu" "F.Paste" "F.Mask")\n\t)'
            % (number, sign * offset, pad_x, pad_y))
    outline = [_outline("F.CrtYd", court_x, court_y, 0.05),
               _outline("F.Fab", body_x, body_y, 0.1)]
    return "\n".join(_footprint_header(
        INDUCTOR_FOOTPRINT_NAME,
        "Bourns SRP4020TA shielded power inductor, recommended layout from "
        "the SRP4020TA series datasheet",
        "inductor shielded SRP4020", "smd", -court_y - 0.8, court_y + 0.8,
        0.8, 0.12, 21) + outline + pads + [')']) + "\n"


def htssop_footprint_text():
    pad_x, pad_y = HTSSOP_PAD_MM
    ep_x, ep_y = HTSSOP_EP_MM
    body_x, body_y = (value / 2.0 for value in HTSSOP_BODY_MM)
    court_x = HTSSOP_ROW_OFFSET_MM + pad_x / 2.0 + HTSSOP_COURTYARD_MARGIN_MM
    court_y = body_y + HTSSOP_COURTYARD_MARGIN_MM
    pads = []
    for number, (x, y) in sorted(htssop_pad_positions_mm().items(),
                                 key=lambda item: int(item[0])):
        pads.append(
            '\t(pad "%s" smd roundrect\n\t\t(at %.4f %.4f)\n'
            '\t\t(size %.3f %.3f)\n\t\t(layers "F.Cu" "F.Paste" "F.Mask")\n'
            '\t\t(roundrect_rratio 0.25)\n\t)' % (number, x, y, pad_x, pad_y))
    pads.append(
        '\t(pad "%s" smd rect\n\t\t(at 0 0)\n\t\t(size %.3f %.3f)\n'
        '\t\t(layers "F.Cu")\n\t\t(property pad_prop_heatsink)\n'
        '\t\t(zone_connect 2)\n\t)'
        % (netlist.DRIVER_PINS["EPAD"], ep_x, ep_y))
    height = mask_window_height_mm()
    for centre in mask_window_centres_mm():
        pads.append(
            '\t(pad "" smd rect\n\t\t(at 0 %.4f)\n\t\t(size %.3f %.3f)\n'
            '\t\t(layers "F.Mask")\n\t)' % (centre, ep_x, height))
        pads.append(
            '\t(pad "" smd rect\n\t\t(at 0 %.4f)\n\t\t(size %.3f %.3f)\n'
            '\t\t(layers "F.Paste")\n\t)' % (centre, ep_x, height))
    marker = (
        '\t(fp_line\n\t\t(start %.3f %.3f)\n\t\t(end %.3f %.3f)\n'
        '\t\t(stroke\n\t\t\t(width 0.12)\n\t\t\t(type default)\n\t\t)\n'
        '\t\t(layer "F.SilkS")\n\t)'
        % (-court_x, -court_y, -court_x + 0.8, -court_y))
    outline = [_outline("F.CrtYd", court_x, court_y, 0.05),
               _outline("F.Fab", body_x, body_y, 0.1)]
    return "\n".join(_footprint_header(
        HTSSOP_FOOTPRINT_NAME,
        "HTSSOP-28 with exposed pad 2.75x6.2 mm; mask and paste cut into "
        "%d windows so the board's thermal vias land on mask dams"
        % HTSSOP_MASK_WINDOWS,
        "HTSSOP TSSOP exposed pad thermal vias", "smd",
        -court_y - 1.0, court_y + 1.0, 1.0, 0.15, 31)
        + outline + [marker] + pads + [')']) + "\n"


def sym_lib_table_text():
    return ('(sym_lib_table\n\t(version 7)\n'
            '\t(lib (name "%s")(type "KiCad")'
            '(uri "${KIPRJMOD}/library/%s.kicad_sym")'
            '(options "")(descr ""))\n)\n'
            % (LIBRARY_NAME, LIBRARY_NAME))


def fp_lib_table_text():
    return ('(fp_lib_table\n\t(version 7)\n'
            '\t(lib (name "%s")(type "KiCad")'
            '(uri "${KIPRJMOD}/library/%s.pretty")(options "")(descr ""))\n)\n'
            % (LIBRARY_NAME, LIBRARY_NAME))


def artifacts():
    return {
        SYMBOL_LIB_PATH: symbol_library_text(),
        os.path.join(FOOTPRINT_DIR, X1SON_FOOTPRINT_NAME + ".kicad_mod"):
            x1son_footprint_text(),
        os.path.join(FOOTPRINT_DIR, KF128_FOOTPRINT_NAME + ".kicad_mod"):
            kf128_footprint_text(),
        os.path.join(FOOTPRINT_DIR, INDUCTOR_FOOTPRINT_NAME + ".kicad_mod"):
            inductor_footprint_text(),
        os.path.join(FOOTPRINT_DIR, HTSSOP_FOOTPRINT_NAME + ".kicad_mod"):
            htssop_footprint_text(),
        SYM_LIB_TABLE: sym_lib_table_text(),
        FP_LIB_TABLE: fp_lib_table_text(),
    }


def write():
    os.makedirs(FOOTPRINT_DIR, exist_ok=True)
    written = []
    for path, text in artifacts().items():
        with open(path, "w", encoding="utf-8", newline="\n") as handle:
            handle.write(text)
        written.append(path)
    return sorted(written)


if __name__ == "__main__":
    for path in write():
        sys.stdout.write(path + "\n")

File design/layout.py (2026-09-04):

"""The board: outline, placement, planes and silkscreen, from the source.

Board coordinates run x right and y UP from the lower-left corner, which is
the frame every dimension here is stated in. KiCad's own y runs down, so the
mapping is applied once, in `to_board`.

The arrangement follows the current. Field wiring enters on the left edge,
the bulk sits along the bottom, and the motor leaves through a connector
directly above the bridge outputs, so the phase conductors are the shortest
structures on the board. The driver sits between them with its exposed pad
on the reference plane, its supply pins taken straight down to the rail
plane, and one sense resistor immediately outside each bridge return.
"""
from __future__ import annotations

import json
import math
import os
import sys

from . import ksym, netlist

_TOOLKIT = os.path.join(
    os.path.dirname(os.path.dirname(os.path.abspath(__file__))),
    "tooling", "PCBA_AutoDesignAndTest")
if _TOOLKIT not in sys.path:
    sys.path.insert(0, _TOOLKIT)

from pcbqa import board as pcbqa_board  # noqa: E402
from pcbqa import headless  # noqa: E402

headless.suppress_blocking_ui()

import pcbnew  # noqa: E402

REPO_ROOT = os.path.dirname(os.path.dirname(os.path.abspath(__file__)))
BOARD_PATH = os.path.join(REPO_ROOT, netlist.PROJECT_NAME + ".kicad_pcb")
PLACEMENT_PATH = os.path.join(REPO_ROOT, "constraints", "placement.json")

FOOTPRINT_SEARCH_PATHS = (
    os.path.join(REPO_ROOT, "library"),
    "/usr/share/kicad/footprints",
)

ORIGIN_MM = (30.0, 110.0)

BOARD_W_MM = 80.0
BOARD_H_MM = 65.0

EDGE_WIDTH_MM = 0.1
TRACK_WIDTH_MM = 0.25
SENSE_TRACK_WIDTH_MM = 1.2
#: The driver's reference pins reach the pad under the device between their
#: neighbours, so this is narrower than anything a search would draw.
DRIVER_GROUND_TRACK_MM = 0.2
CLEARANCE_MM = 0.15
EDGE_CLEARANCE_MM = 0.3
VIA_DIAMETER_MM = 0.6
VIA_DRILL_MM = 0.3
ZONE_INSET_MM = 0.5
STITCH_TRACK_WIDTH_MM = 0.4
STITCH_GAP_MM = 0.35

MOUNTING_HOLES_MM = {
    "H1": (3.5, 3.5),
    "H2": (76.5, 3.5),
    "H3": (3.5, 61.5),
    "H4": (76.5, 61.5),
}

#: Parts a placement search may not move, and why.
#:
#: The connectors and the fasteners are the board's mechanical contract. The
#: test points are its service contract. The driver's position is what the
#: exposed pad's connections are generated from, and the two sense resistors
#: are the pair whose position IS the topology they create.
LOCKED_REFERENCES = tuple(sorted(
    [reference for reference in netlist.PARTS
     if reference[0] in ("J", "H") and reference[1:].isdigit()]
    + [reference for reference in netlist.PARTS
       if reference.startswith("TP")]
    + ["U1"] + list(netlist.SENSE_RESISTOR_REFERENCES.values())))

PLACEMENT = {
    # the input: terminal on the left edge, then the reverse-blocking
    # device, its gate divider and the clamp
    "J1": (7.0, 25.0, 90.0),
    "Q1": (20.0, 25.0, 0.0),
    "R1": (18.0, 31.0, 0.0),
    "R2": (22.0, 31.0, 0.0),
    "D1": (26.0, 24.0, 90.0),
    "TP1": (26.0, 30.5, 0.0),
    "TP9": (30.0, 30.5, 0.0),

    # the bulk row along the bottom, feeding the rail plane
    "C1": (14.0, 9.0, 0.0),
    "C2": (28.0, 9.0, 0.0),
    "C20": (42.0, 9.0, 0.0),
    "C21": (56.0, 9.0, 0.0),

    # the driver, its decoupling, its charge pump and its sense resistors
    "U1": (46.0, 24.0, 0.0),
    "RS2": (36.0, 27.575, 180.0),
    "RS1": (56.0, 27.575, 0.0),
    "C5": (32.0, 24.2, 0.0),
    "C6": (60.0, 24.5, 0.0),
    "C3": (32.0, 17.5, 0.0),
    "C4": (60.0, 21.0, 0.0),
    "C7": (36.5, 24.2, 0.0),
    "C8": (32.0, 21.0, 0.0),
    "C9": (36.5, 21.5, 180.0),
    "C10": (56.0, 24.0, 0.0),
    "C11": (56.0, 21.0, 0.0),
    "TP7": (54.5375, 30.5, 0.0),
    "TP8": (37.4625, 30.5, 0.0),
    "TP10": (34.0, 33.0, 0.0),
    "TP13": (54.5375, 33.5, 0.0),

    # the motor connector, directly above the bridge outputs
    "J2": (57.88, 40.0, 180.0),

    # the logic regulator
    "U3": (66.0, 20.0, 0.0),
    "L1": (72.0, 25.0, 0.0),
    "C12": (66.0, 15.0, 0.0),
    "C13": (71.0, 15.0, 0.0),
    "C14": (66.0, 25.0, 0.0),
    "C15": (66.0, 29.0, 0.0),
    "C16": (70.0, 29.0, 0.0),
    "R3": (76.0, 20.0, 90.0),
    "R4": (76.0, 16.0, 90.0),
    "R5": (61.0, 29.0, 0.0),
    "R6": (61.0, 32.0, 0.0),
    "TP2": (76.0, 25.0, 0.0),
    "TP11": (76.0, 29.0, 0.0),

    # the controller and everything referenced to the logic rail
    "U2": (30.0, 46.0, 0.0),
    "C17": (20.0, 42.0, 0.0),
    "C18": (20.0, 45.0, 0.0),
    "C19": (20.0, 48.0, 0.0),
    "R7": (14.0, 42.0, 0.0),
    "R8": (14.0, 45.0, 0.0),
    "R13": (14.0, 48.0, 0.0),
    "R9": (40.0, 45.0, 0.0),
    "R10": (40.0, 48.0, 0.0),
    "R11": (40.0, 51.0, 0.0),
    "R12": (44.0, 51.0, 0.0),
    "TP3": (10.0, 37.0, 0.0),
    "TP4": (17.0, 37.0, 0.0),
    "TP5": (24.0, 37.0, 0.0),
    "TP6": (31.0, 37.0, 0.0),
    "TP12": (10.0, 41.0, 0.0),

    # the indicators
    "D10": (9.0, 60.0, 0.0),
    "R20": (13.0, 60.0, 0.0),
    "D11": (9.0, 57.0, 0.0),
    "R21": (13.0, 57.0, 0.0),

    # the headers along the top edge, each conductor's series element and
    # clamp between the header and what it reaches
    "R16": (20.0, 60.0, 0.0),
    "R17": (24.0, 60.0, 0.0),
    "R14": (28.0, 60.0, 0.0),
    "R15": (32.0, 60.0, 0.0),
    "R18": (36.0, 60.0, 0.0),
    "R19": (40.0, 60.0, 0.0),
    "R22": (44.0, 60.0, 0.0),
    "D2": (20.0, 57.0, 0.0),
    "D3": (24.0, 57.0, 0.0),
    "D4": (28.0, 57.0, 0.0),
    "D5": (32.0, 57.0, 0.0),
    "D6": (36.0, 57.0, 0.0),
    "D7": (40.0, 57.0, 0.0),
    "D8": (44.0, 57.0, 0.0),
    "D9": (48.0, 57.0, 0.0),
    "J4": (55.0, 61.0, 0.0),
    "J3": (62.0, 61.0, 0.0),
    "J5": (69.0, 61.0, 0.0),
}


def to_board(x_mm, y_mm):
    return (ORIGIN_MM[0] + x_mm, ORIGIN_MM[1] - y_mm)


def _point(x_mm, y_mm):
    bx, by = to_board(x_mm, y_mm)
    return pcbnew.VECTOR2I(pcbnew.FromMM(bx), pcbnew.FromMM(by))


def accepted_placement():
    if not os.path.isfile(PLACEMENT_PATH):
        return {}
    with open(PLACEMENT_PATH, encoding="utf-8") as handle:
        document = json.load(handle)
    return {reference: tuple(pose)
            for reference, pose in document["placement"].items()
            if reference not in LOCKED_REFERENCES}


def seed_placement():
    placed = dict(PLACEMENT)
    for reference, (x, y) in MOUNTING_HOLES_MM.items():
        placed[reference] = (x, y, 0.0)
    return placed


def fixed_placements():
    placed = seed_placement()
    for reference, pose in accepted_placement().items():
        if reference not in placed:
            raise KeyError("accepted placement names an unknown part: "
                           + reference)
        placed[reference] = pose
    missing = sorted(reference for reference, part in netlist.PARTS.items()
                     if part["footprint"] and reference not in placed)
    if missing:
        raise KeyError("no placement for " + ", ".join(missing))
    return placed
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

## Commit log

2026-08-30 Seed benchmark board 08/32 from its supplied brief
    PCBA_StepperController is one of thirty-two boards in the PCBA_AutoDesignAndTest
    benchmark. This commit establishes the repository and nothing else:
    the board is not designed, and its absence is the intended state.
    BRIEF.md is the supplied brief, preserved byte for byte and
    authoritative. board/requirements.json splits it into fixed_requirements
    -- each carrying the verbatim brief text that substantiates it, bound to
    the SHA-256 of the brief's bytes -- and open_decisions, which are the
    design agent's to make and to record as choices. Promoting a decision
    into a requirement is the failure the split exists to prevent.
    docs/architecture.md is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
2026-08-30 Stop the scaffold claiming a check it does not perform
    An external review of the pushed benchmark found this repository asserting
    three things about itself that were not true as shipped.
    board/manifest.template.json said running the validator against it "will
    fail on the missing source". It does not: `run.py validate
    board/manifest.template.json` exits 0 and prints ACCEPTED, with all 36 gates
    NOT_APPLICABLE and no gate reading sources.pcb, so the absent board file is
    never noticed. The template now says exactly that, under verdict_warning,
    and docs/status.md and CLAUDE.md carry the same warning where a reader and
    an agent will actually meet it. The toolkit is behaving as designed - a gate
    w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
2026-08-30 Remove the claim-audit skill, and the instructions that called it
    Requested. .claude/skills/claim-audit/ is deleted, and with it every
    reference: CLAUDE.md's publishing discipline no longer names it, and the
    README layout table no longer advertises it.
    accountability-review kept calling it at step 3, which would have left the
    surviving skill invoking one that is not in the clone - the same
    dangling-instruction defect that put these skills in the repository in the
    first place. That step now states the claim-binding work directly: scan the
    drafts for claim-bearing words, and bind each to an artifact recomputed on
    the spot rather than to the process that produced it. The discipline is
    unchange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
2026-08-30 Finish removing claim-audit: the last prose reference to it
    accountability-review still explained itself with "that is why the claim
    audit runs first". Nothing runs first any more - the claim binding is step 3
    of this skill, and it runs before the review package is assembled, not
    before the review. The sentence now says that.
    Removing a skill is not done when its file is gone. It is done when nothing
    left in the repository tells a reader to go and find it.
2026-08-30 Review against this repository's own invariants, not another board's
    /accountability-review assembled its review package with a hardcoded list
    of "standing invariants", and that list belonged to a different project and
    an abandoned workflow: "never modify the authoritative Board A PCB" names a
    board that does not exist here, and "never touch main" and "no PRs"
    describe a process the opposite of this one -- every repository in this
    benchmark is developed on main and pushed directly.
    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
2026-08-30 Delete generated prose; keep the seed brief and machine-consumed config
    The seed pack already contained the human-authored specification for this
    board. Everything this repository added on top was a reinterpretation of it:
    a README and CLAUDE.md narrating the brief, an architecture worksheet of
    English questions, status and sources documents, a prose requirements
    document, and requirements.json - which restated the brief as English
    requirement strings and copied 20-odd verbatim quotations back out of a file
    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
2026-09-03 Design the stepper controller to a validated, fabricable board
    Everything is generated from design/: the netlist and the parts, the symbols
    and footprints this board owns, the placement and every conductor the design
    rather than the search is responsible for, the schematic, the board, the
    requirement claims, the thermal and simulation documents, the fabrication
    selection, and the manifest the toolkit is pointed at.
    The driver is a TMC2226 with external shunts, chosen against recorded
    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
    [bom.csv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]
2026-09-03 Record what this board needed from the toolkit and did not have
2026-09-03 Rebind the release to the phase 0 toolkit
    The toolkit now validates every manifest against its published schema
    and refuses vocabulary it does not implement, so the board-local gate
    list moves under the x_ extension prefix; gate-class selection
    (--only=design) supersedes it. Regenerated and revalidated against
    toolkit f4d3904: 25 gates pass, 11 report NOT_APPLICABLE, and
    the fabrication record now carries the source-closure member map, so
    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
    [stepper_controller-B_Cu.gbr, stepper_controller-B_Mask.gbr, stepper_controller-B_Silkscreen.gbr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]
2026-09-03 Retire the hand-written routing acceptance list
    The toolkit's design gate class replaces it: candidate acceptance now
    selects --only=design, expanded by the toolkit, so the set cannot rot
    as gates are added. The list leaves the manifest and the generator that writes it, and the
    release is regenerated under toolkit b441685, which also closes the
    review findings on the phase 0 seams: 25 gates pass, 11 report
    NOT_APPLICABLE.
    [stepper_controller-B_Cu.gbr, stepper_controller-B_Mask.gbr, stepper_controller-B_Silkscreen.gbr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]
2026-09-03 Close the adversarial findings that reached this board
    The unread keys the manifest carried are gone: tolerance_seconds is
    deleted, contact_semantics becomes the note annotation it always was,
    and the schema now refuses both by name. The routing acceptance
    selection regains ROUTE.PROVENANCE - the loop writes the record before
    judging, so record-board agreement is judged per candidate as it was
    under the hand-written list. Regenerated and revalidated under
    toolkit a0f53eb: 25 gates pass, 11 report NOT_APPLICABLE.
    [stepper_controller-B_Cu.gbr, stepper_controller-B_Mask.gbr, stepper_controller-B_Silkscreen.gbr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]
2026-09-03 Rebind the release to toolkit 0c051f2
    The toolkit keeps its CLI alive with no display and closes the third
    review round's findings; nothing in this board's own sources moved.
    25 gates pass, 11 report NOT_APPLICABLE.
    [stepper_controller-B_Cu.gbr, stepper_controller-B_Mask.gbr, stepper_controller-B_Silkscreen.gbr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]
2026-09-03 Rebind the release to toolkit 7f51066
    The panel-fix round widened the source closure to every staged design
    input and hardened the verdict binding, so the fabrication outputs and
    the recorded verdict are regenerated under the new toolkit. The
    transient .pcbqa-hold-* lock file is ignored.
    The orientation registry's review provenance the toolkit never reads
    (review basis, margins, pairing, references) moves under x_-prefixed
    keys, regenerated through this board's own emitter; the toolkit's
    schema now admits exactly the fields its registry reader consumes.
    [stepper_controller-B_Cu.gbr, stepper_controller-B_Mask.gbr, stepper_controller-B_Silkscreen.gbr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]
2026-09-04 Delete the routing loop, declare the search, rebind to toolkit bd0ad78
    The 990-line private loop and design/tidy.py move to the toolkit; the
    declaration is generated by design/manifest.py - plane and phase nets
    reserved, two-layer search, the 4-orderings-by-3-clearances ladder and
    the 0.05 mm grid this board's fine-pitch escape measured out. The
    text-splice restore, phase-per-subprocess resilience and locked-copper
    protection this board pioneered are now toolkit behaviors verified by
    the toolkit's own tests. layout.write() saves through the
    project-preserving save.
    The fabrication outputs are regenerated under the new toolkit: exports
    are now timestamp-free and the archive metadata is fixed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
    [stepper_controller-B_Cu.gbr, stepper_controller-B_Mask.gbr, stepper_controller-B_Silkscreen.gbr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]
2026-09-04 Accept through the design gate class; courtyards; no raw endpoints
    The re-review held the plan to its words: "routing accepts nothing
    release will reject" means the acceptance names the design gate
    class, not a counter subset - so it now does, beside the counters.
    placement.courtyard is declared for both faces (edge clearance is
    not: this board places connectors or mounting holes at its outline
    by design, and reports that reason instead of promising a margin).
    The remaining raw GetStart()/GetEnd() reads go through
    pcbqa.board.endpoints - Phase 1.1's exit criterion, now literal.
    design/route.py is deleted per the plan; `run.py route` is the
    entry. Fabrication binding refreshed under the revie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
    [geometry.py, manifest.py]
2026-09-04 Write the placement board through the project-preserving save
    The toolkit review's Phase 1.6 sweep found this board's unused
    placement-writer helper still calling pcbnew.SaveBoard directly -
    which rewrites, or invents, sibling project documents beside whatever
    path it is given. `write_placement_board` now goes through
    `pcbqa.board.save` like every other board write, and a test pins that
    no design module calls SaveBoard directly again. Revalidated under
    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
2026-09-05 Refresh the fabrication binding under the reviewed toolkit
    The toolkit's fourth review round pinned the routing judgment to its
    recorded policy at the read site, fixed the router-summary shape the
    reconciliation reads, and extended post-adoption enforcement to the
    manifest digest and recorded plan; nothing in this board's own sources
    changed. Rebuilt and revalidated so the committed verdict and closure
    name the reviewed toolkit state.
2026-09-05 Refresh the fabrication binding under the reviewed toolkit
    The toolkit's fifth review round closed its last blocker: with a
    recorded binding declared, every acceptance gate now reads the
    verified staged design instead of live pathnames. Nothing in this
    board's own sources changed. Rebuilt and revalidated so the committed
    verdict and closure name the reviewed toolkit state.
2026-09-05 Refresh the fabrication binding under the reviewed toolkit
    The toolkit's sixth review round bound every auxiliary file the
    routing acceptance gates consume - stackup supplements, contract
    documentation, simulation records - into the routing record, enforced
    at adoption, check, provenance and replay; nothing in this board's
    own sources changed. Rebuilt and revalidated so the committed verdict
    and closure name the reviewed toolkit state.
2026-09-05 Declare the claim policy and the derived-document generators this board asked for
    The derived-document machinery 08's own request filed (a
    manifest-declared regeneration order, and a gate that re-runs each
    generator and compares) is now real: all eight derived documents -
    claims, thermal, the extracted model set and the five simulation
    scenarios - regenerate byte-identical under PROV.DERIVED_DOCUMENTS,
    each generator honoring PCBQA_OUT, and run.py regenerate refreshes
    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
2026-09-05 Refresh the fabrication binding under the committed Phase 2 toolkit
    The toolkit's evidence-governance commit is a source-closure member,
    so the committed artifacts and verdict re-bind to it. Nothing in this
    board's own sources changed in this commit.
2026-09-05 Move the governance declarations into the manifest generator
    The board's own committed-manifest-is-generated test caught what the
    finishing pipeline had swallowed: the Phase 2 manifest blocks were
    scripted onto board/manifest.json while design/manifest.py still
    generated the old document. The blocks now live in design/governance
    as data the generator merges, the evidence index gains its new frozen
    entry through design/evidence.py rather than by hand, the committed
    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
2026-09-05 Adopt the round-2 review corrections: expiring dependencies, shared registry
    Open external dependencies gain review dates (owned and expiring
    applies to both permission paths), and the simulation registry is
    assembled through pcbqa.sim.assemble - the gate entry point - instead
    of a local construction, so tests and gates agree by construction.
    [simulation.py]
2026-09-05 Adopt the round-3 corrections: the claim document joins the closure
    The claim document the verdict rests on joins the source closure, so
    a release tag carries it and its movement is a named staleness. The
    claims generator declaration is now mandatory toolkit-side
    (CLAIM.MATRIX refuses an unlisted document), which this board already
    satisfied.
2026-09-05 Refresh the fabrication binding: round-3 verdict rendering
    The toolkit's open-item rendering commit is a closure member; this
    board's committed verdict re-binds to it. No board sources changed.
2026-09-05 Refresh the fabrication binding: fourth-round evidence fixes
    The toolkit now lists register methods still required that no
    dependency owns as open items in the policy state - a passing claim
    establishes the number, never the separately declared method - and the
    refreshed validation record carries whatever this board honestly owes.
2026-09-05 Refresh the fabrication binding: fifth-round toolkit
    Domain enforcement now owns timing's evidence gates, refuses vacuous
    simulation declarations, and judges device-parameter validity from the
    operating point; nothing on this board changes beyond the closure.
2026-09-05 Refresh the fabrication binding: sixth-round toolkit
    PROV.DEVICE_PARAMETERS now judges applicability from the citation
    rather than from the presence of a validity range - a record with no
    stated range has no supported range. Nothing on this board changes
    beyond the closure; its citations already state their operating points.
2026-09-05 Re-freeze against the advanced fabricator catalogue
    Phase 3.1 published seven more capabilities from the SAME frozen
    evidence - hole plating thickness, the PTH annular ring, and the
    soldermask process set - so the approved catalogue's normalized digest
    moved from 953f02ea to e504b0de. Every physical input this board froze
    records the catalogue state it was resolved from, so those records were
    re-frozen against the current one.
    Nothing this board selects changed: the process selection came back
    byte-identical apart from the digest, and no physical value moved. The
    new capabilities describe plating and soldermask, which this board's
    selection does not turn on.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
2026-09-05 Decide, on the record, about the five domains Phase 3 added
    Phase 3 implements thermal, current capacity, power integrity,
    differential pair and reference continuity as evidence domains, so
    saying nothing about them is no longer a neutral act: silence lands the
    policy state on requires-additional-evidence.
    This board declines all five, each with a reason true of THIS board -
    what it does instead, or why the domain does not describe it. It cannot
    honestly declare them: declaring one means authoring a capacity basis, a
    set of thermal-resistance records or a rail mesh, and inventing any of
    that is precisely the fabrication this toolkit exists to prevent. Where
    the board already answers the que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
2026-09-05 Refresh the fabrication binding against the reviewed Phase 3 toolkit
    The toolkit is a source-closure member, so four rounds of adversarial
    review over Phase 3 mean the committed reports and the validation record
    are re-made against the code that now exists. Nothing about this board
    changed.
2026-09-06 Rebuild the artifacts against the fifth-review toolkit
    No verdict moves and no gate changes status: the round closed defects in
    the current, PDN, coverage and arc paths, and what this board exercises
    of them it already exercised correctly. The artifacts are refreshed so
    the recorded run names the toolkit commit that produced it rather than
    one four fixes behind.
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2026-09-06 Rebuild the artifacts against the review-response toolkit
    No verdict moves and no gate changes status. The round closed the
    island-barrel channel in the PDN mesh, scoped the thermal copper
    ceiling to a named pad, and corrected two verdict texts; what this
    board exercises of them it already exercised correctly, and the refresh
    binds the record to the toolkit commit that produced it.
2026-09-06 Rebuild the artifacts against the second-pass toolkit
    No verdict moves and no gate changes status. The pass closed the
    untested through-hole half of the island-barrel filter and composed
    every standing THERMAL.DERATING problem into its verdict; what this
    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
2026-09-06 Rebuild the artifacts against the fragility-knob toolkit
    No verdict moves and no gate changes status. The toolkit pins
    KICAD_PLANE_FRAGILITY_COST=0 for every FUTURE owned search - KiCad's
    zone filler is a thread race the field inherited, core pinning
    measurably does not close it, and disabling the field is deterministic
    by construction. This board's adopted route and record are untouched:
    the knob binds searches, not validations, and a replay of the old
    record now refuses the environment check as it should. The refresh
    binds the artifacts to the toolkit commit that produced them.
2026-09-07 Rebuild the artifacts against the fill-oracle-account toolkit
    No verdict moves and no gate changes status. The wrapper now refuses a
    router summary that cannot account for which pour geometry its
    fragility field used; this board's adopted route and record are
    untouched, and the refresh binds the artifacts to the toolkit commit
    that produced them.
2026-09-07 Rebuild the artifacts against the upstream-merged toolkit
    No verdict moves and no gate changes status. The pinned router advanced
    through 254 upstream commits (grid_router v0.22.0, the #831 fill-oracle
    account the wrapper now reads, the --clearance semantics split); this
    board's adopted route and record are untouched, future searches inherit
    the new semantics, and the refresh binds the artifacts to the toolkit
    commit that produced them.
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2026-09-11 Decide the two Phase 4 domains, and stop carrying a copy of the deriver
    Phase 4 added two evidence domains - `lifecycle` and `assembly_process` -
    and this board mentioned neither, which the policy record reads as
    silence rather than as a decision. It now decides both, and adopts the
    request it filed itself (08-8).
    The assembly process is declared: one reflow pass, 250 C peak, top side,
    no wash, with the five through-hole connectors fitted afterwards. Every
    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
    [stepper_controller-B_Cu.gbr, stepper_controller-B_Mask.gbr, stepper_controller-B_Silkscreen.gbr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]
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2026-09-12 Decide Phase 5's new domain, and make the next one fail a test
    `flow_repeatability` arrived declinable, and this board cannot produce
    the study it asks for. Measured, not assumed:
    - The adopted copper came from KiCadRoutingTools 0.21.5 with grid_router
    0.21.4 under KiCad 10.0.5. This tree resolves 0.22.0, 0.22.0 and
    10.0.6. FLOW.REPEATABILITY refuses a study whose router identity is
    not the adopted record's, so any distribution measurable today is
    about a tool this board's copper did not come from.
    - The search's input board was never committed - no commit of
    stepper_controller.kicad_pcb hashes to the record's source_sha256 - so
    the distribution that produced this copper cannot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
